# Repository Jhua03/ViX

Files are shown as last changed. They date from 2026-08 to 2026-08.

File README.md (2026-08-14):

# Parker ViX250AH / ViX500AH + Raspberry Pi Pico 2 Controller

A practical, safety-oriented reference implementation for controlling a **Parker ViX250AH or ViX500AH** from a computer and a **Raspberry Pi Pico 2**.

The architecture deliberately separates configuration/status from real-time motion:

- a Raspberry Pi 5, laptop, desktop, or other USB-capable computer talks to **ViX X3 over RS-232**;
- the same computer talks to a **Pico 2 over USB**;
- the Pico 2 generates differential **STEP/DIR** for **ViX X4**, reads the X4 encoder copy, and supervises limits, ViX fault, E-stop, following error, and the X4 energise input.

This repository targets the **AH family only**. It is intended to work with both the **ViX250AH** and **ViX500AH**. Motor/encoder tuning is machine-specific; the included MX80L setup is an example, not a universal ViX tuning profile.

> **Safety:** a servo drive can move unexpectedly during setup, wiring mistakes, or controller development. Commission near the middle of travel, use a physical emergency stop, keep clear of moving hardware, and verify every input polarity before allowing motion. Do not copy the MX80L gains to a different motor/stage without validating them.

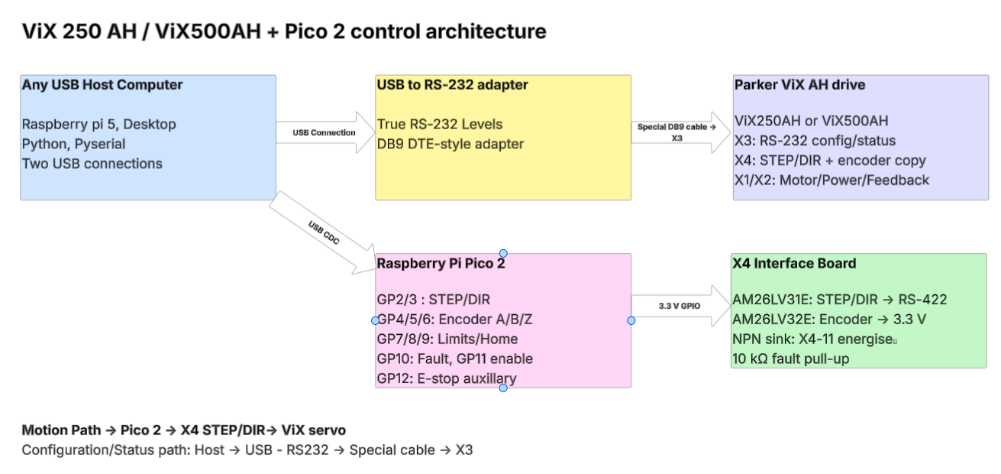
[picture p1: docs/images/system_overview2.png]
System overview


## Start here

1. Read [Hardware and wiring](docs/hardware-and-wiring.md).
2. Build the special [X3 RS-232 cable](docs/serial-x3.md).
3. Build the low-voltage [Pico 2 ↔ X4 interface](hardware/connector-pinouts.md) using the included schematic.
4. Follow [Software setup](docs/software-setup.md) to install Python/`pyserial` and flash the Pico 2.
5. Read [Safety](docs/safety.md) before energising the drive.
6. Follow [Commissioning](docs/commissioning.md) for first power-up and first controlled move.

## Repository layout

```text
ViX/
├── README.md
├── CHANGELOG.md
├── docs/                       User guide split by topic
│   └── images/                 Embedded SVG/PNG diagrams
├── hardware/
│   ├── schematic/              KiCad electrical source
│   ├── ViX_AH_Pico2_Wiring.drawio
│   ├── connector-pinouts.md
│   └── bom.md
├── datasheets/                 Parker + TI manufacturer PDFs
├── firmware/                   Pico 2 firmware
├── host/                       Simple supported Python CLI
├── scripts/                    Firmware build/upload helpers
├── tests/                      Offline checks for the cleaned repo
└── archive/commissioning-history/
                                Original v4.x development/commissioning material
```

## Hardware at a glance

For the X4 electrical interface this design uses:

- **AM26LV31E** — 3.3 V differential line driver for STEP/DIR;
- **AM26LV32E** — 3.3 V differential receiver for A/B/Z encoder copies;
- a small **NPN transistor** for fail-safe control of X4 pin 11;
- pull-ups for open-collector inputs where required.

See [the BOM](hardware/bom.md) for exact suggested parts, DigiKey Canada links, construction options, and local datasheets.

For breadboard work, the SOIC-16 ICs can be soldered to inexpensive **SOIC-16-to-DIP-16 adapter boards**. The adapters can be plugged into a breadboard, mounted on perfboard, **or used by themselves with wires soldered directly to their 0.1-inch pads**.

## X3 is not a normal straight-through DB9 cable

The ViX X3 connector uses an RS-232 pin assignment that is not the standard PC DB9 arrangement. A simple three-wire adapter cable is required.

For a typical USB-to-RS232 adapter with a male DB9 connector:

```text
USB-RS232 DB9            ViX X3
pin 3  TX   -----------> pin 4  RX
pin 2  RX   <----------- pin 5  TX
pin 5  GND  ------------ pin 3  GND
```

A convenient build uses a **female DB9 screw-terminal/breakout** at the USB-RS232 side and a **male DB9 breakout** at the ViX X3 side. See [X3 serial cable](docs/serial-x3.md) before building it; several X3 pins must intentionally remain unconnected.

## Simple host utility

Install the Python dependency:

```bash
python3 -m venv .venv
source .venv/bin/activate
python -m pip install -r requirements.txt
```

Typical commands:

```bash
python host/vix.py info --vix-port /dev/ttyUSB0 --pico-port /dev/ttyACM0 --axis 1
python host/vix.py status --vix-port /dev/ttyUSB0 --pico-port /dev/ttyACM0 --axis 1
python host/vix.py configure --profile io-only --confirm-inputs
python host/vix.py disable
```

The `jog` command intentionally requires explicit safety acknowledgements and currently uses the validated **MX80L 10 nm/count example profile**. Read [host/README.md](host/README.md) and [Commissioning](docs/commissioning.md) before using it.

## Documentation

- [Documentation index](docs/README.md)
- [Hardware and wiring](docs/hardware-and-wiring.md)
- [X3 serial connection and custom cable](docs/serial-x3.md)
- [Software setup](docs/software-setup.md)
- [ViX configuration](docs/vix-configuration.md)
- [Pico protocol and GPIO](docs/pico-protocol.md)
- [Safety and shutdown](docs/safety.md)
- [Commissioning](docs/commissioning.md)
- [MX80L tuning and measured performance](docs/tuning-and-performance.md)
- [Troubleshooting](docs/troubleshooting.md)

## Schematics and source files

The low-voltage X4 interface is supplied in three useful forms:

- **KiCad**: [`hardware/schematic/vix_pico_interface.sch`](hardware/schematic/vix_pico_interface.sch) — editable electrical schematic source;
- **SVG/PNG**: [`docs/images/x4_interface.svg`](docs/images/x4_interface.svg) — easy to read directly on GitHub;
- **draw.io**: [`hardware/ViX_AH_Pico2_Wiring.drawio`](hardware/ViX_AH_Pico2_Wiring.drawio) — high-level system, X3 cable, and X4 wiring diagrams.

X1 high-voltage/motor power and X2 motor-feedback wiring are intentionally not recreated as breadboard wiring. Use the correct Parker motor/harness and the included Parker manual for those connectors.

## Tested example: Parker MX80L, 10 nm encoder

The archived commissioning work used an MX80L configuration with:

```text
100,000 encoder counts/mm
100 counts = 1 µm
1 count = 10 nm
```

The current example tuning and measured small-move limitations are documented separately in [Tuning and performance](docs/tuning-and-performance.md). This separation is intentional: the electrical interface is generic to the supported ViX AH drives, while encoder scale and servo tuning depend on the attached motor/stage.

## Historical material

The original v4.x threshold-refinement package, release notes, audits, and agent handoff are preserved under [`archive/commissioning-history/`](archive/commissioning-history/). They are kept for traceability but are not the recommended starting point for a new user.

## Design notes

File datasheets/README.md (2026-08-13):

# Datasheets

| File | Component | Manufacturer page / purchase link |
|---|---|---|
| `Parker_ViX_AH_User_Guide.pdf` | Parker ViX AH servo-drive user guide | Original Parker manual supplied with this repository |
| `TI_AM26LV31E.pdf` | AM26LV31E 3.3 V differential line driver | https://www.ti.com/product/AM26LV31E |
| `TI_AM26LV32E.pdf` | AM26LV32E 3.3 V differential line receiver | https://www.ti.com/product/AM26LV32E |

DigiKey Canada purchase pages used by the hardware guide:

- AM26LV31EIDR: https://www.digikey.ca/en/products/detail/texas-instruments/AM26LV31EIDR/1895997
- AM26LV32EIDR: https://www.digikey.ca/en/products/detail/texas-instruments/AM26LV32EIDR/1896009

The local PDFs are included so the wiring can be reviewed offline. Check the manufacturer pages for later datasheet revisions before a new hardware spin.

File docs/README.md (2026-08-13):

# Documentation index

The original long-form ViX document has been reorganized into these task-focused guides:

| Document | Use it for |
|---|---|
| [Hardware and wiring](hardware-and-wiring.md) | System architecture, X4 electronics, construction choices |
| [X3 serial connection](serial-x3.md) | USB-RS232 adapter and the special three-wire DB9 cable |
| [Software setup](software-setup.md) | Python, `pyserial`, Pico 2 firmware build/flash |
| [ViX configuration](vix-configuration.md) | AH drive mode, X4 settings, volatile setup, readback |
| [Pico protocol](pico-protocol.md) | GPIO mapping, ASCII/JSON protocol, watchdog, status fields |
| [Safety](safety.md) | E-stop, enable/shutdown order, limits, faults |
| [Commissioning](commissioning.md) | First connection through first safe move |
| [Tuning and performance](tuning-and-performance.md) | MX80L 10 nm example only |
| [Troubleshooting](troubleshooting.md) | Serial, fault, encoder, limit, and motion problems |

For connector-level tables, use [`../hardware/connector-pinouts.md`](../hardware/connector-pinouts.md). For the parts list, use [`../hardware/bom.md`](../hardware/bom.md).

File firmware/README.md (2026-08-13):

# Pico 2 firmware

Firmware identity:

```text
vix-base-pico2-v2.7
protocol 5
```

This firmware is for **Raspberry Pi Pico 2 only**. It generates X4 STEP/DIR,
counts the ViX encoder copy, supervises limits/fault/E-stop/following error, and
controls the X4 hardware-energise transistor.

The authoritative GPIO mapping is in `src/board_config.h` and is summarized in
[`../hardware/connector-pinouts.md`](../hardware/connector-pinouts.md).

## Build

From the repository root, create/activate a Python environment and install
PlatformIO if you do not already have it:

```bash
python3 -m venv .venv
source .venv/bin/activate
python -m pip install --upgrade pip platformio
```

Install the native build prerequisites for your OS (CMake, Ninja and an Arm
embedded GCC toolchain), install/clone the official Raspberry Pi Pico SDK, then:

```bash
export PICO_SDK_PATH="$HOME/pico-sdk"
bash scripts/build_and_verify_firmware.sh
```

The expected output is:

```text
firmware/build-pio/vix_base_pico2_controller.uf2
```

The PlatformIO project is only a task/front-end; the actual firmware build is
performed by the official Pico SDK CMake/Ninja project.

## Upload

For the first upload, hold **BOOTSEL** while plugging the Pico 2 into USB, then
run:

```bash
bash scripts/upload_firmware_bootsel.sh
```

You can also copy the UF2 manually to the Pico 2 mass-storage device.

## Guarded recovery is advanced commissioning functionality

The firmware contains:

```text
RECOVER START <100..2000 ms> I_UNDERSTAND
RECOVER STOP
```

This path was developed for tightly bounded recovery from particular stale ViX
fault states. It is separate from normal `ARM`/`ENABLE` and is **not** part of
the beginner commissioning workflow in the main guide.

Firmware independently bounds that recovery path with timeout, displacement,
heartbeat, E-stop/limit, encoder-validity, and fault-state checks. The normal
`ENABLE 1` path still refuses an active fault or safety latch.

For the full development rationale and tests, see
[`../archive/commissioning-history/v4_78/`](../archive/commissioning-history/v4_78/).

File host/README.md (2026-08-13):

# `vix.py` host utility

`vix.py` is the small, supported starting point for a ViX250AH/ViX500AH + Pico 2 installation. It is intentionally much simpler than the archived threshold-refinement runner.

## Install

From repository root:

```bash
python3 -m venv .venv
source .venv/bin/activate
python -m pip install -r requirements.txt
```

## Architecture

The process opens two independent serial links:

```text
--vix-port   USB-to-RS232 -> custom DB9 cable -> ViX X3
--pico-port  USB -> Pico 2
```

Motion is generated only by Pico STEP/DIR over X4. The script does not use ViX internal motion commands.

## Commands

### Identity

```bash
python host/vix.py info --vix-port /dev/ttyUSB0 --pico-port /dev/ttyACM0 --axis 1
```

### Status

```bash
python host/vix.py status --axis 1
```

### Apply volatile I/O configuration

```bash
python host/vix.py configure \
  --profile io-only \
  --confirm-inputs \
  --axis 1
```

The command leaves the drive OFF and Pico disarmed.

### MX80L 10 nm example configuration

```bash
python host/vix.py configure \
  --profile mx80l-10nm \
  --confirm-inputs \
  --axis 2
```

Only use this profile on a system you have validated for the included MX80L parameters.

### One complete jog transaction

```bash
python host/vix.py jog \
  --um 1 \
  --confirm-inputs \
  --i-understand \
  --axis 2
```

`jog` currently requires the `mx80l-10nm` profile. It performs the full enable/move/safe-disable transaction in one process so the watchdog heartbeat remains alive and shutdown is deterministic.

### Safe disable

```bash
python host/vix.py disable --axis 1
```

## Bench E-stop bypass

`--bench-no-estop` exists only for attended commissioning before a final E-stop auxiliary input is available. Do not use it for a completed machine.

## Soft limits and negative limit

Defaults are:

```text
--soft-min -50000
--soft-max  50000
```

Add `--has-negative-limit` only after a real negative-limit input has been physically tested. The archived MX80L machine had no working negative-limit input and used `HAS_LN=0`.

## What this utility intentionally does not do

It does not:

- save tuning/configuration with `SV`;
- change motor/feedback setup with `MOTOR`, `SETUPFB`, or `RFS`;
- perform ViX internal motion;
- run the advanced guarded stale-fault recovery workflow;
- claim that one motor's gains are safe for another motor.

For advanced historical characterization tools, see `archive/commissioning-history/v4_78/`.

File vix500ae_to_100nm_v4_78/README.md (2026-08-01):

# vix500ae_to_100nm_v4_78

Targeted threshold-refinement package for the ViX500AE/Base + MX80L + Pico2 setup.

Use after v4.77 found the best strong threshold at 40 counts / 400 nm using:

```text
damped_gi0p2_gp2_gv1p5_cl2
GF0 GI0.2 GP2 GV1.5 FT0, CL=2%
```

Run:

```bash
./scripts/run_offline_checks.sh

python3 host/vix100nm_commission.py \
  --stage 8 \
  --vix-port /dev/ttyUSB0 \
  --pico-port /dev/ttyACM0 \
  --bench-no-estop

./scripts/run_threshold_refinement.sh
```

Default amplitudes are 50, 40, 35, 30, 25, 20, 15, 10 counts, equal to 500, 400, 350, 300, 250, 200, 150, 100 nm.

The sweep validates the 400 nm threshold and tests conservative current/gain nudges:

```text
damped_gi0p2_gp2_gv1p5_cl2
damped_gi0p2_gp2_gv1p5_cl3
damped_gi0p2_gp2_gv1p5_cl4
damped_gi0p3_gp2_gv1p5_cl3
```

This is not final 100 nm validation. It is a threshold-refinement test to see whether the usable threshold can be pushed from 400 nm toward 300/250/200 nm. Stay present; the script commands real moves.

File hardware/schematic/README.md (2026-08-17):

# KiCad schematic

Keep `vix_pico_interface-cache.lib` in the **same directory** as the schematic. The schematic uses the cached custom symbols for the Pico 2, AM26LV31E, AM26LV32E, and the ViX X4 connector.

## Opening it

1. Keep both files together:
   - `vix_pico_interface.sch`
   - `vix_pico_interface-cache.lib`
2. Open `vix_pico_interface.sch` in KiCad Schematic Editor.
3. KiCad 8/9 may offer to convert it to the current `.kicad_sch` format. Save the converted copy if desired.

## What is represented

- GP2/GP3 -> AM26LV31E -> ViX X4 differential STEP/DIR.
- ViX X4 A/B/Z differential encoder outputs -> AM26LV32E -> GP4/GP5/GP6.
- X4 FAULT open-collector output -> GP10 with 10 kOhm pull-up to 3.3 V.
- GP11 -> 4.7 kOhm -> 2N3904 -> X4 ENERGISE input for `ES=0` operation.
- Pico GND is tied to X4 pin 3 control 0 V.
- GP7/GP8/GP9/GP12 are labelled for external limit, home, and E-stop auxiliary inputs.

This sheet is **only the low-voltage X4 interface**. The host computer communicates with the ViX separately through X3 RS-232.

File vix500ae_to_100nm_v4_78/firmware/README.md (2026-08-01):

# Pico 2 firmware v2.7

Identity:

```text
vix-base-pico2-v2.7
protocol 5
```

## Guarded recovery command

```text
RECOVER START <100..2000 ms> I_UNDERSTAND
RECOVER STOP
```

This command is separate from normal ARM/ENABLE. It may assert GP11 while the
ViX fault input is already active, solely so recoverable DF20/DF21 can enter a
valid enabled state and clear.

Firmware independently enforces:

- 2000 ms absolute maximum;
- 5000 counts / 50 µm raw displacement;
- 750 ms host heartbeat;
- E-stop and limits;
- invalid quadrature transitions;
- timeout latch;
- fault-clear then fault-reassert shutdown.

The normal `ENABLE 1` path still refuses an active fault or safety latch.

## Build and upload

From the package root:

```bash
source ~/Downloads/vix250ah_pico2_controller_v1/.venv/bin/activate
export PICO_SDK_PATH="$HOME/pico-sdk"
export PICOTOOL_EXECUTABLE="$HOME/.local/picotool-2.3.0/bin/picotool"
bash scripts/build_and_verify_firmware.sh
```

Expected output:

```text
firmware/build-pio/vix_base_pico2_controller.uf2
```

Then put the Pico 2 in BOOTSEL mode and run:

```bash
bash scripts/upload_firmware_bootsel.sh
```

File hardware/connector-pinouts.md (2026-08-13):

# Connector and Pico pinouts

## Pico 2 pins used by the included firmware

The firmware uses GPIO numbers, not header pin numbers. For the standard non-wireless Raspberry Pi Pico 2 board:

| Function | GPIO | Pico physical header pin |
|---|---:|---:|
| STEP logic | GP2 | 4 |
| DIR logic | GP3 | 5 |
| Encoder A | GP4 | 6 |
| Encoder B | GP5 | 7 |
| Encoder Z | GP6 | 9 |
| Positive limit | GP7 | 10 |
| Negative limit | GP8 | 11 |
| Home | GP9 | 12 |
| ViX fault | GP10 | 14 |
| Drive enable command | GP11 | 15 |
| E-stop auxiliary | GP12 | 16 |
| 3.3 V output | 3V3(OUT) | 36 |
| Ground | GND | 3, 8, 13, 18, 23, 28, 33, or 38 |

## ViX X3 - RS-232

X3 is a 9-way D-sub **socket** on the drive.

| X3 pin | Function | Use here |
|---:|---|---|
| 1 | Reserved | No connection |
| 2 | Drive reset/mode input | **Do not connect** during normal operation |
| 3 | RS-232 GND | Special cable ground |
| 4 | RS-232 Rx | From USB-RS232 adapter TX |
| 5 | RS-232 Tx | To USB-RS232 adapter RX |
| 6 | Reserved | No connection |
| 7 | RS-232 Tx (D-loop) | No connection for a single drive |
| 8 | Do not connect | **No connection** |
| 9 | +5 V output | **No connection** |

See [`../docs/serial-x3.md`](../docs/serial-x3.md) for the special cable.

## ViX X4 - STEP/DIR, encoder copy, fault and energise

X4 is a high-density 15-way D-sub socket. Use a **male HD15** mating connector or screw-terminal breakout.

| X4 pin | With `EI=0` / `EO=2` | Pico interface |
|---:|---|---|
| 3 | Control 0 V | Pico/interface GND |
| 4 | /Z encoder output | U2 receiver Z- |
| 5 | Z encoder output | U2 receiver Z+ |
| 6 | Fault, NPN open collector | GP10 + 10 kΩ pull-up to 3.3 V |
| 7 | STEP- input | U1 STEP- |
| 8 | DIR- input | U1 DIR- |
| 9 | A- encoder output | U2 A- |
| 10 | B- encoder output | U2 B- |
| 11 | Energise input | Q1 collector; active-low when `ES=0` |
| 12 | STEP+ input | U1 STEP+ |
| 13 | DIR+ input | U1 DIR+ |
| 14 | A+ encoder output | U2 A+ |
| 15 | B+ encoder output | U2 B+ |

X4 pins 1 and 2 are analogue-input pins and are not used by this controller.

## U1 - AM26LV31E wiring

| U1 pin | Name | Connection |
|---:|---|---|
| 1 | 1A | Pico GP2 STEP |
| 2 | 1Y | X4 pin 12 STEP+ |
| 3 | 1Z | X4 pin 7 STEP- |
| 4 | G | 3.3 V (enable drivers) |
| 5 | 2Z | X4 pin 8 DIR- |
| 6 | 2Y | X4 pin 13 DIR+ |
| 7 | 2A | Pico GP3 DIR |
| 8 | GND | GND |
| 9 | 3A | GND (unused channel input) |
| 10, 11 | 3Y, 3Z | No connection |
| 12 | /G | GND (enable drivers) |
| 13, 14 | 4Z, 4Y | No connection |
| 15 | 4A | GND (unused channel input) |
| 16 | VCC | 3.3 V + 100 nF to GND |

## U2 - AM26LV32E wiring

| U2 pin | Name | Connection |
|---:|---|---|
| 1 | 1B | X4 pin 9 A- |
| 2 | 1A | X4 pin 14 A+ |
| 3 | 1Y | Pico GP4 encoder A |
| 4 | G | 3.3 V (enable receivers) |
| 5 | 2Y | Pico GP5 encoder B |
| 6 | 2A | X4 pin 15 B+ |
| 7 | 2B | X4 pin 10 B- |
| 8 | GND | GND |
| 9 | 3B | X4 pin 4 Z- |
| 10 | 3A | X4 pin 5 Z+ |
| 11 | 3Y | Pico GP6 encoder Z |
| 12 | /G | GND (enable receivers) |
| 13 | 4Y | No connection |
| 14, 15 | 4A, 4B | No connection |
| 16 | VCC | 3.3 V + 100 nF to GND |

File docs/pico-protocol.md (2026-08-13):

# Pico 2 firmware, GPIO and protocol

## 1. GPIO mapping

The included firmware uses:

```text
GP2   STEP logic -> AM26LV31E -> X4 STEP pair
GP3   DIR logic  -> AM26LV31E -> X4 DIR pair
GP4   encoder A  <- AM26LV32E <- X4 A pair
GP5   encoder B  <- AM26LV32E <- X4 B pair
GP6   encoder Z  <- AM26LV32E <- X4 Z pair
GP7   positive limit
GP8   negative limit
GP9   home
GP10  ViX X4 fault
GP11  NPN hardware-enable control for X4 pin 11
GP12  E-stop auxiliary input
```

For physical header numbers, see [`../hardware/connector-pinouts.md`](../hardware/connector-pinouts.md).

## 2. USB serial format

The Pico uses native USB CDC, normally at `/dev/ttyACM0` on Linux. The host sends:

- ASCII text commands;
- newline termination;
- one command at a time.

The Pico answers with one-line JSON objects. The host checks the `ok` field and treats a rejected command as an error.

## 3. Core commands

| Command | Purpose |
|---|---|
| `PING` | basic communication check |
| `INFO` | firmware/system identity |
| `STATUS` | full current state |
| `CONFIG SHOW` | report configuration |
| `CONFIG <KEY> <VALUE>` | change runtime configuration |
| `ZERO` | zero the Pico encoder/command frame while disabled |
| `ARM I_UNDERSTAND` | arm after checks |
| `DISARM` | disarm |
| `ENABLE 0/1` | control the X4 hardware-enable transistor |
| `MOVE ...` | generate one STEP/DIR move |
| `ABORT` | abort motion |
| `CLEAR` | clear ordinary latches when allowed |
| `DIAG CLEAR` | clear diagnostic state |
| `HB` | watchdog heartbeat |

The archived commissioning firmware also contains a tightly bounded guarded-recovery command for specific stale ViX fault states. That is an advanced commissioning feature and is intentionally not part of the beginner workflow.

## 4. MOVE command

```text
MOVE <delta_counts> <max_rate_counts_s> <accel_counts_s2> <move_id>
```

`move_id` should be nonzero and unique. The host waits for both:

```text
motion == IDLE
move_completed_id == requested move_id
```

before treating a move as complete.

## 5. Runtime configuration used by the simple CLI

The generic Pico configuration includes:

```text
CONFIG LPOL 1
CONFIG LNPOL 0
CONFIG HPOL 1
CONFIG FPOL 1
CONFIG ENCSIGN 1
CONFIG DIRINV 0
CONFIG ESTOPREQ 1
CONFIG SOFTMIN -50000
CONFIG SOFTMAX 50000
CONFIG FERRMAX 5000
CONFIG WATCHDOG_MS 750
```

`HAS_LN`, `ESTOPREQ`, and `CONFIRM_INPUTS` are selected from CLI arguments. `ENCSIGN=1` matches the latest included firmware/wiring package; older long-form notes that said `-1` are superseded for this repository state.

## 6. Heartbeat

When armed/enabled, the host sends `HB` approximately every 100 ms. The default watchdog is 750 ms. The heartbeat runs in a separate thread so a blocked main command loop does not silently stop watchdog service.

A heartbeat is **not** a substitute for the explicit shutdown sequence. On exit or error, the host still attempts ABORT, hardware-disable, DISARM, and ViX OFF.

## 7. Useful STATUS fields

Expect fields such as:

```text
motion
armed
enabled
zeroed
latched
latch
encoder_position
command_position
following_error
encoder_invalid
limit_pos_active
limit_neg_active
home_active
fault_active
estop_safe
move_completed_id
```

Treat an unexpected increase in `encoder_invalid`, a latch, a ViX fault, an unsafe limit/E-stop, or excessive following error as a reason to stop commissioning and diagnose the hardware.

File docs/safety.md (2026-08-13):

# Safety and shutdown policy

This repository controls a real servo drive. Software safety is supplementary to physical guarding, correct power wiring, a real emergency-stop circuit, and the ViX's own protections.

## Non-negotiable software rules

1. Keep the ViX **OFF** while changing configuration.
2. Do not use ViX internal motion commands for this controller; motion goes through Pico `MOVE` and X4 STEP/DIR.
3. Do not issue `SV`, `MOTOR`, `SETUPFB`, or `RFS` from the normal host workflow.
4. The Pico hardware-enable path must be active **before** sending ViX `ON`.
5. Remove Pico hardware enable **before** sending ViX `OFF` during shutdown.
6. Abort on any safety latch, ViX fault, active movement limit, invalid encoder transition increase, E-stop, communication failure, or operator stop.
7. Do not automatically resume after a safety latch. Require operator inspection/acknowledgement.
8. Use a real E-stop auxiliary input in the completed machine.
9. Treat gain/current changes and initial energisation as hazardous operations.

## Normal enable sequence

A safe commissioning transaction follows this order:

```text
1. Open Pico and ViX serial ports.
2. ViX OFF.
3. Apply X4 configuration.
4. Read back ViX configuration.
5. Configure Pico while disabled/disarmed.
6. Clear permitted latches/diagnostics.
7. ZERO while disabled.
8. ARM.
9. Start heartbeat.
10. Pico ENABLE 1.
11. Wait briefly (~50 ms).
12. ViX ON.
13. Allow servo pull-in/settling.
14. Re-read status before commanding motion.
```

Do not send `ZERO` after the Pico is armed/enabled; use a software coordinate offset if you need a local GUI zero after energisation.

## Shutdown / fault sequence

The software attempts every step independently so one communication failure does not prevent later stop actions:

```text
Pico ABORT
Pico ENABLE 0
Pico DISARM
ViX OFF
stop heartbeat
```

After a fault, record Pico status and the ViX fault word before clearing diagnostic evidence.

## E-stop policy

For a completed machine, run with E-stop supervision required. Bench bypass (`--bench-no-estop`) exists only for attended commissioning where the final auxiliary contact is not yet wired. Do not make bench bypass the normal production configuration.

The included example assumes a normally-closed E-stop auxiliary loop whose broken/pressed state becomes unsafe. Physically verify your implementation before trusting it.

## Limits and soft limits

Hard limit inputs protect travel only if they are physically installed, wired, and configured with the correct polarity. Software soft limits add another layer but are relative to the coordinate origin established by the controller.

The included generic default `-50000..+50000` counts is intentionally a small commissioning window. On the MX80L 10 nm example that equals ±0.5 mm. For another encoder scale it represents a different physical distance.

## First energisation

Do it near the center of travel with:

- the mechanism mechanically clear;
- a physical E-stop within immediate reach;
- conservative current/tuning already established for the attached motor;
- verified encoder direction and limit polarity;
- no person or fragile equipment in the path.

If the stage pulls hard in one direction, chatters, runs away, or the encoder sign is wrong, disable immediately and diagnose before trying again.

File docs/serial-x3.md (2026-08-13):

# ViX X3 serial connection and custom DB9 cable

## 1. Host-side equipment

You need:

- any USB-capable host computer (Raspberry Pi 5, laptop, desktop, mini PC, etc.);
- a **true USB-to-RS232 adapter** that produces RS-232 electrical levels;
- the custom three-wire DB9 cable described below;
- a second USB cable for the Pico 2.

A USB-to-TTL/UART adapter is **not** the same thing as USB-to-RS232 and should not be connected directly to X3.

## 2. Why a special cable is required

ViX X3 is a DB9-style 9-way D-sub socket, but its RS-232 pins are not arranged like a standard PC serial DB9. Therefore a normal straight-through DB9 extension cable is not the documented connection.

X3 custom cable

For a standard PC-style USB-RS232 adapter whose DB9 uses pin 3 as TX, pin 2 as RX, and pin 5 as signal ground:

| USB-RS232 DB9 | Direction | ViX X3 |
|---|---|---|
| pin 3 TX | → | pin 4 RX |
| pin 2 RX | ← | pin 5 TX |
| pin 5 GND | — | pin 3 RS-232 GND |

Only these three conductors are required for a single-drive connection.

## 3. Easy cable build using two breakouts

For the common USB-RS232 adapter with a **male DB9** plug:

- use a **female DB9 screw-terminal/breakout** on the adapter side;
- use a **male DB9 screw-terminal/breakout** on the ViX side because X3 on the drive is a socket;
- connect only three wires:

```text
female breakout pin 3  -> male breakout pin 4
female breakout pin 2  -> male breakout pin 5
female breakout pin 5  -> male breakout pin 3
```

Label both ends before closing the cable. Continuity-check every pin with a multimeter before plugging it into the drive.

If your particular USB-RS232 adapter has a different connector gender, change only the mechanical mating arrangement; preserve the **signal-to-X3 mapping** above.

## 4. X3 pins to leave alone

For this project:

| X3 pin | Action |
|---:|---|
| 1 | no connection |
| 2 | **do not connect** during normal operation; this is associated with drive reset/mode behavior |
| 3 | RS-232 ground — use |
| 4 | RS-232 receive — use |
| 5 | RS-232 transmit — use |
| 6 | no connection |
| 7 | D-loop transmit — not needed for a single drive |
| 8 | **do not connect** |
| 9 | +5 V output — no connection |

## 5. Serial settings

The included host software uses:

```text
9600 baud
8 data bits
no parity
1 stop bit
no flow control
```

ViX commands are ASCII and are terminated by a carriage return (`\r`). The software axis address prefixes the command; for example, with axis address 1 the revision query is sent as `1R(RV)\r`.

The tested machine used axis address 2, but the CLI defaults to 1 because that is a common single-drive configuration. Always query/confirm the actual drive address and pass `--axis` explicitly when needed.

## 6. Linux device names

Typical Linux enumeration is:

```text
/dev/ttyUSB0   USB-to-RS232 adapter -> ViX X3
/dev/ttyACM0   Pico 2 native USB CDC
```

These names can change after reconnecting hardware. Use `ls -l /dev/ttyUSB* /dev/ttyACM*` or stable udev symlinks if this will become a permanent machine.

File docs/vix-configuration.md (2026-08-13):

# ViX250AH / ViX500AH configuration

## 1. What is generic and what is motor-specific

The X4 I/O mode is generic to this repository's ViX AH architecture. Servo gains, current limits, encoder scale, tracking limits, and motion acceptance criteria depend on the attached motor/stage.

The supported CLI therefore offers:

- `--profile io-only`: configure the ViX X4 interface only;
- `--profile mx80l-10nm`: additionally apply the included tested MX80L example tuning.

## 2. X4 interface configuration

The host sets the drive OFF before applying configuration and uses:

```text
MP
W(ES,0)
W(EI,0)
W(EO,2)
```

Meaning:

| Setting | Meaning in this project |
|---|---|
| `MP` | position mode for external pulse/direction control |
| `ES=0` | X4 energise input is active-low |
| `EI=0` | X4 command input uses STEP/DIR |
| `EO=2` | X4 encoder copy provides A/B quadrature outputs |

The host reads these values back before it will proceed with a motion transaction.

## 3. Volatile setup policy

The simple host utility intentionally does **not** issue:

```text
SV
MOTOR
SETUPFB
RFS
```

The guide assumes a drive whose motor/feedback base configuration has already been established correctly. Experiment-specific I/O/tuning values are applied volatilely so a commissioning mistake does not silently become the drive's permanent boot configuration.

## 4. Typical serial commands

Commands are prefixed with the ViX software axis address. Examples shown for axis 1:

```text
1R(RV)       read software revision
1STATUS      status report
1R(DF)       drive-fault word
1R(UF)       user-fault word (be aware of clear-on-read behavior in the ViX manual)
1OFF         de-energise
1ON          energise, only after the Pico hardware-enable path is safe and active
```

## 5. MX80L 10 nm example profile

Only use this profile with a machine whose motor/encoder/stage has actually been validated for it:

```text
GF = 0
GI = 0.2
GP = 2
GV = 1.5
FT = 0
CL = 2
PC = 100
TL = 13000
IM = 1
IW = 1000
```

The CLI applies these after setting `MP`, `ES=0`, `EI=0`, and `EO=2` when `--profile mx80l-10nm` is selected.

See [Tuning and performance](tuning-and-performance.md) for the example machine's scale and measured limitations.

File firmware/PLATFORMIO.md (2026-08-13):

# PlatformIO / official Pico SDK workflow

PlatformIO is used only as a convenient command/task front-end. The firmware is
configured and compiled by the official Raspberry Pi Pico SDK for
`PICO_BOARD=pico2`.

## Requirements

Install:

- Python 3 and PlatformIO;
- CMake;
- Ninja;
- an Arm embedded GCC toolchain;
- the Raspberry Pi Pico SDK.

Example Python setup:

```bash
python3 -m venv .venv
source .venv/bin/activate
python -m pip install --upgrade pip platformio
export PICO_SDK_PATH="$HOME/pico-sdk"
```

On Fedora, the native packages are typically along the lines of CMake, Ninja,
`arm-none-eabi-gcc*`, and newlib; exact package names vary by Fedora release.

## Command-line build

From repository root:

```bash
bash scripts/build_and_verify_firmware.sh
```

The script discovers `pio` from `PIO_EXECUTABLE`, the active `PATH`, or the
usual `~/.platformio/penv/bin/pio` location.

The resulting UF2 is:

```text
firmware/build-pio/vix_base_pico2_controller.uf2
```

## VS Code

Open the **repository root** or `firmware/` in VS Code with the PlatformIO
extension. The environment is named:

```text
pico2_official_sdk
```

The custom tasks are:

```text
SDK Build
SDK Upload
```

For the first upload, put the Pico 2 in BOOTSEL mode. Later upload behavior can
use picotool when the host permissions are configured.

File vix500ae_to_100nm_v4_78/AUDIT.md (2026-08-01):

# v4.10 engineering audit

## Verdict on v3

v3 was not ready for powered commissioning. The most important defect was that
it asserted the X4 enable input but never issued the required ViX `ON` command.
The zero-gain and gain-hold stages could therefore appear stable while the motor
was not energised.

Additional problems found were missing stage-order enforcement, a default gain
fallback, incomplete fault/invalid checks during shams, delayed Ctrl+C handling,
and acceptance criteria that relied too heavily on medians and sham span.

## Corrective actions in v4

1. Added X4-enable + serial-`ON` transaction and ST2.1 confirmation.
2. Added strict stage prerequisites and hardware/software state fingerprinting.
3. Removed guessed gains.
4. Added complete-run invalid-transition, latch, and DF checks.
5. Added bracketed Pico/ViX endpoint acquisition.
6. Added 95th-percentile and repeatability gates for the final 100 nm claim.
7. Added sham absolute-motion gates, not only sham range.
8. Added immediate KeyboardInterrupt cleanup.
9. Added mocked integration and adversarial offline tests.

## Known physical constraints retained

- Limit+ works: raw 1 active, raw 0 inactive.
- Limit- is unavailable and disabled by policy.
- Home works: raw 1 active, raw 0 inactive.
- No automatic homing or end search.
- Every powered stage creates a local zero and limits commands to +/-0.5 mm.
- Operator must confirm at least 1 mm physical clearance in both directions.
- Initial HE500 current clamp remains 1% to 2%, approximately 0.15 A to 0.30 A
  under the audited configuration.

## Release decision

Use v4.10 only. Flash Pico v2.3, run the offline checks, and run Stage 0. Do not run
Stage 1 until Stage 0 passes and the E-stop/hardware disconnect is ready.

## Additional v4.10 review

A second audit found no new route to bypass the staged gates, but added two
defensive controls before hardware release: explicit local target alignment using
`W(PA,0)` while OFF, and strict post-test proof that both the Pico enable output
and ViX ST2.1 are de-energised. Powered results are rejected if ST2.1 drops
unexpectedly during the measurement.

## v4.10 findings from the additional audit

The v4.1 release was not accepted unchanged. Two defects were found:

- **Pass-state/cleanup ordering:** stage functions wrote pass state before the
  context-manager cleanup. Cleanup errors were suppressed, so a failed
  de-energisation or restore could coexist with a saved pass flag.
- **Direction-probe baseline timing:** the initial encoder baseline was captured
  before energisation and could include enable-settling displacement.

v4.10 introduces strict cleanup error propagation, stage-in-progress crash
recovery, failure-driven downstream invalidation, and a post-energisation
direction baseline. It also expands exact Pico and ViX preflight readback.

## v4.19 audit note

The previous 234/250 result was caused by asynchronous PA/PE sampling. v4.19 forbids target inference from an unbracketed PA or PE value and preserves every accepted/rejected bracket in evidence.

## v4.19 forward audit

The following downstream failure modes were reviewed before release:

- slow zero-target settling from the Stage 2 gain;
- asynchronous PA/PE target reconstruction;
- opposite target sign before DIRINV correction;
- estimator precision tighter than serial timing supports;
- fixed waits in coarse, fine, and 100 nm ABBA tests;
- trace overflow when adaptive settling lengthens a block;
- Pico/ViX endpoint comparison at different timestamps;
- shams with unrealistically short dwell;
- carrying the Stage 2 hold gain into all later motion stages;
- stale Stage 3/downstream state after a gain or sign change.

The host now records a separate `motion_gains` state value selected by Stage 3.
Stages 4-7 cannot silently fall back to an uncharacterized higher gain.

## Final forward-audit findings corrected

1. Added an explicit v4.19 commissioning-policy fingerprint and v4.18 migration,
   preventing a previous Stage 3 pass from bypassing the new gain/settling rules.
2. Forced the first ABBA block to precede all shams and made trace selection
   deterministic.
3. Removed the 3-second sham cap; sham timing now follows measured settling up to
   the amplitude-specific endpoint budget.
4. Corrected current-firmware instructions to v2.6/protocol 5 and retained v2.5
   only as clearly labelled historical context.
5. Corrected the Stage 3 prompt to match the actual 20 µm hold and 50 µm probe
   safety windows.

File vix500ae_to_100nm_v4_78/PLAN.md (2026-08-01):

# ViX500AE + MX80L route to encoder-side 100 nm motion — v4.10

## Confirmed starting state

- Target drive: ViX500AE-Base, custom product CP13269 rev 3, HE500.
- Saved motor definition corrected to the 10 nm MX80L-D13 definition:
  `MOTOR(49420,1.6,1300000,138,80,4.75,1.80,4.500)`.
- ViX X4 quadrature copy and the Pico PIO count agreed exactly over more than
  1.5 million counts in both directions.
- Limit+ works and is active-high at the Pico input: raw 1 at the limit, raw 0 away from it.
- Limit- does not work and is excluded from the safety policy.
- Home works and is active-high: raw 1 at home, raw 0 away from home.
- Initial motion stays inside a manually centred +/-0.5 mm software window.

## Why firmware v2.3 is required

The v2.3 firmware adds four safeguards/measurement features before powered
commissioning:

1. A 750 ms host heartbeat lease. Loss of the laptop process disables X4-11.
2. Continuous following-error and limit checks even while holding with no MOVE
   active.
3. A real invalid-quadrature-transition counter driven by a rare-event PIO IRQ.
4. A 1 kHz on-Pico trace buffer for command position, encoder position,
   following error, invalid count, motion state and safety state.

## Stage gates

### Stage 0 - Input and identity preflight

No motion and no enable.

- Verify exact drive identity, corrected MOTOR definition, 75-85 V motor bus,
  and all DF bytes zero.
- Apply the runtime Pico policy:
  - `LPOL=1`
  - `HPOL=1`
  - `HAS_LN=0`
  - `FPOL=1`
  - `ENCSIGN=1`
  - software window `[-50000,+50000]` counts
  - watchdog 750 ms
- Require Limit+ to be inactive (`raw=0`) before arming.
- Home may read 0 or 1 depending on carriage location; it is a reference input,
  not a hard-stop input.

Gate: all checks pass.

### Stage 1 - Zero-gain enable smoke

- ViX temporary mode: MP, EI=0, EO=2, ES=0.
- `GAINS(0,0,0,0,0)`.
- CL=1% on HE500, approximately 0.15 A maximum.
- No STEP pulse. A pass is impossible unless the drive is confirmed energised.
- Start heartbeat, assert X4 enable, issue `ON`, and require `R(ST2)` to show ST2.1 motor-energised. Enable for 0.5 s with Pico trace, then drop X4 enable before `OFF`.

Purpose: validate X4 enable, fault polarity and absence of an enable transient
or unexpected torque before asking the position loop to hold.

Gate: no DF, no latch, no invalid transitions and no displacement beyond the
50 um firmware cutoff.

### Stage 2 - Low-gain hold ladder

Test, in order:

1. GP=0.10, GV=0.10
2. GP=0.25, GV=0.25
3. GP=0.50, GV=0.50
4. GP=1.00, GV=0.75
5. GP=2.00, GV=1.00

GF=GI=FT=0 during this stage. Each candidate is enabled for 1.5 s at CL=1%.
The stiffest stable candidate is repeated for 3 s at CL=2%, approximately
0.30 A maximum.

Gate: actual energisation confirmed, no fault/latch/invalid transition, no runaway, and bounded tail motion.
The selected gains are stored in `~/vix100nm_state.json`.

### Stage 3 - Direction and scale probe

- Command +1000 pulses, equal to 10 um at 10 nm/count.
- Rate 1000 counts/s.
- Compare Pico encoder change and ViX PA change.
- If direction is reversed, disable, toggle `DIRINV`, re-zero and retry once.

Gate:

- positive commanded response;
- 1000 +/- 5 encoder counts;
- Pico and ViX changes agree within 2 counts.

### Stage 4 - Coarse functional ladder

ABBA tests at:

- 100 um = 10000 counts
- 10 um = 1000 counts
- 1 um = 100 counts

CL=2%, local +/-0.5 mm window, both directions, no-command shams and first-block
1 kHz traces.

Gate: correct direction on every leg, response within 2% or five counts,
Pico/ViX agreement within two counts, clean faults and invalid counter.

### Stage 5 - Fine screening ladder

ABBA plus sham tests at:

- 1 um = 100 counts
- 500 nm = 50 counts
- 200 nm = 20 counts
- 100 nm = 10 counts

The runner stops at the first amplitude that fails. This is an efficient screen,
not the final 100 nm claim.

### Stage 6 - Final 100 nm validation

- 24 ABBA blocks.
- 96 commanded 10-count legs.
- 12 interleaved no-command sham holds.
- 100 counts/s, so each 100 nm command is generated over 0.1 s.

Gate:

- at least 95% correct-direction responses;
- median response 8-12 counts;
- no more than one wrong-direction leg;
- median ABBA closure <=3 counts;
- Pico/ViX path disagreement <=2 counts;
- sham span <=6 counts;
- no drive faults and no invalid quadrature transitions.

Passing this stage supports the statement: **the system commanded and measured
100 nm using its own 10 nm encoder path**. It is not independent physical
metrology because no interferometer is present.

### Stage 7 - Optional 30 nm / 20 nm stretch tests

Only after Stage 6 passes:

- 30 nm = 3 counts
- 20 nm = 2 counts
- 32 ABBA blocks and 20 shams per amplitude

These are quantised encoder-count experiments. They should not be described as
independently verified physical displacement.

## What remains deliberately excluded

- Automatic homing.
- Negative-limit search.
- Full-travel motion.
- Non-volatile gain or mode changes.
- MOTOR, SETUPFB, RFS or SV commands.
- Current above the initial CL=2% commissioning clamp.

## Mandatory ordering and reset policy

The runner refuses to enter a stage unless the preceding stage is recorded as passed for the exact drive/MOTOR/Pico fingerprint. Rerunning an earlier stage clears all later pass flags so stale evidence cannot unlock 100 nm validation.

## Fault recovery gate

Each stage begins by clearing only stale DF bit 20/21 signatures in a verified
non-energising transaction. Any other DF bit prevents commissioning from
continuing.

## Stage 3 v4.19 decision logic

The small probe classifies independent sign domains before evaluating final
settling. ViX PT is the command-domain reference, ViX PA is the drive feedback
reference, and the Pico encoder copy is compared against PA. The full probe only
passes after command scale, physical direction, cross-reader agreement, and
settling are all independently demonstrated.

## Guarded recovery gate added in v4.19

Any preflight DF20/DF21 is handled before motion-stage setup by the bounded
Pico v2.6 recovery transaction described in the release notes. No other DF is
automatically cleared.

## v4.19 Stage 3 decision path

1. Coherent 250-count sign probe. 2. Apply ENCSIGN/DIRINV correction. 3. Three coherent 250-count verifications. 4. Slower-rate diagnosis only after repeated mismatch. 5. 1000-count adaptive settling.

## v4.19 execution plan

1. Preserve passed Stages 0-2.
2. Run all bounded zero-target motion-gain candidates.
3. Select the best stable candidate using PE, tail span, and settling time.
4. Resolve encoder-copy sign and STEP/DIR direction independently.
5. Verify signed 250-count commands at the fastest passing STEP rate.
6. Verify signed 1000-count commands.
7. Reuse the selected motion gain for adaptive coarse/fine/final ABBA stages.
8. Stop only for a real safety, integrity, tuning-range, or acceptance failure;
   do not stop for a single missing serial payload, a moving target-estimator
   bracket, or a fixed dwell expiring.

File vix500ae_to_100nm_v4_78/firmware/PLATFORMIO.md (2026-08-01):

# PlatformIO / official Pico SDK workflow

The PlatformIO project is only a VS Code task front-end. The firmware itself is
built by the official Raspberry Pi Pico SDK for `PICO_BOARD=pico2`.

## Requirements

```bash
sudo dnf install -y cmake ninja-build arm-none-eabi-gcc-cs \
  arm-none-eabi-gcc-cs-c++ arm-none-eabi-newlib
export PICO_SDK_PATH="$HOME/pico-sdk"
```

Open VS Code from the shell that contains `PICO_SDK_PATH`:

```bash
code /path/to/vix500ae_to_100nm_v4_20/firmware
```

Use:

```text
Project Tasks -> pico2_official_sdk -> Custom -> SDK Build
Project Tasks -> pico2_official_sdk -> Custom -> SDK Upload
```

The resulting file is:

```text
build-pio/vix_base_pico2_controller.uf2
```

For the first upload, hold BOOTSEL while connecting the Pico 2. Later uploads
can use picotool when Fedora udev permissions are installed.

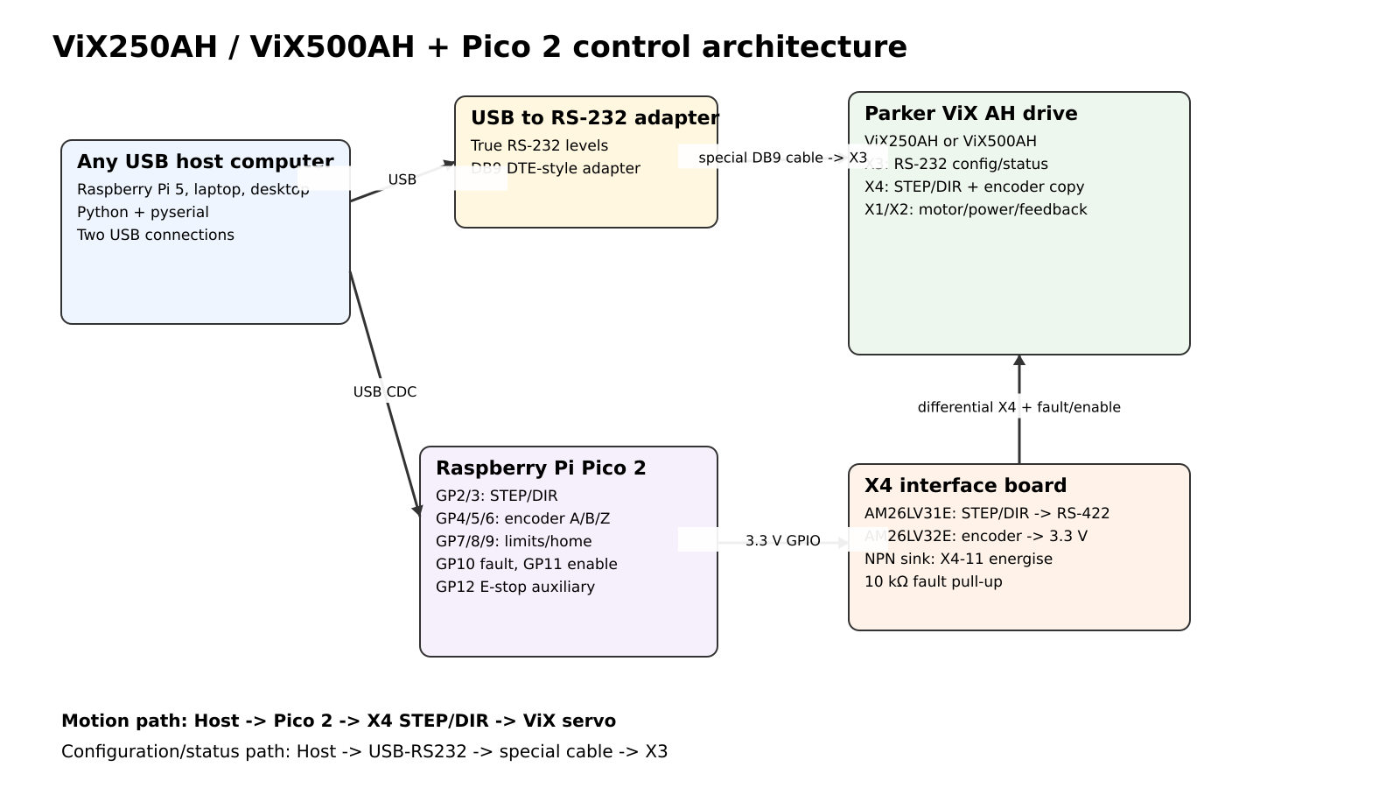
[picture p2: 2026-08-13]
docs/images/system_overview.png

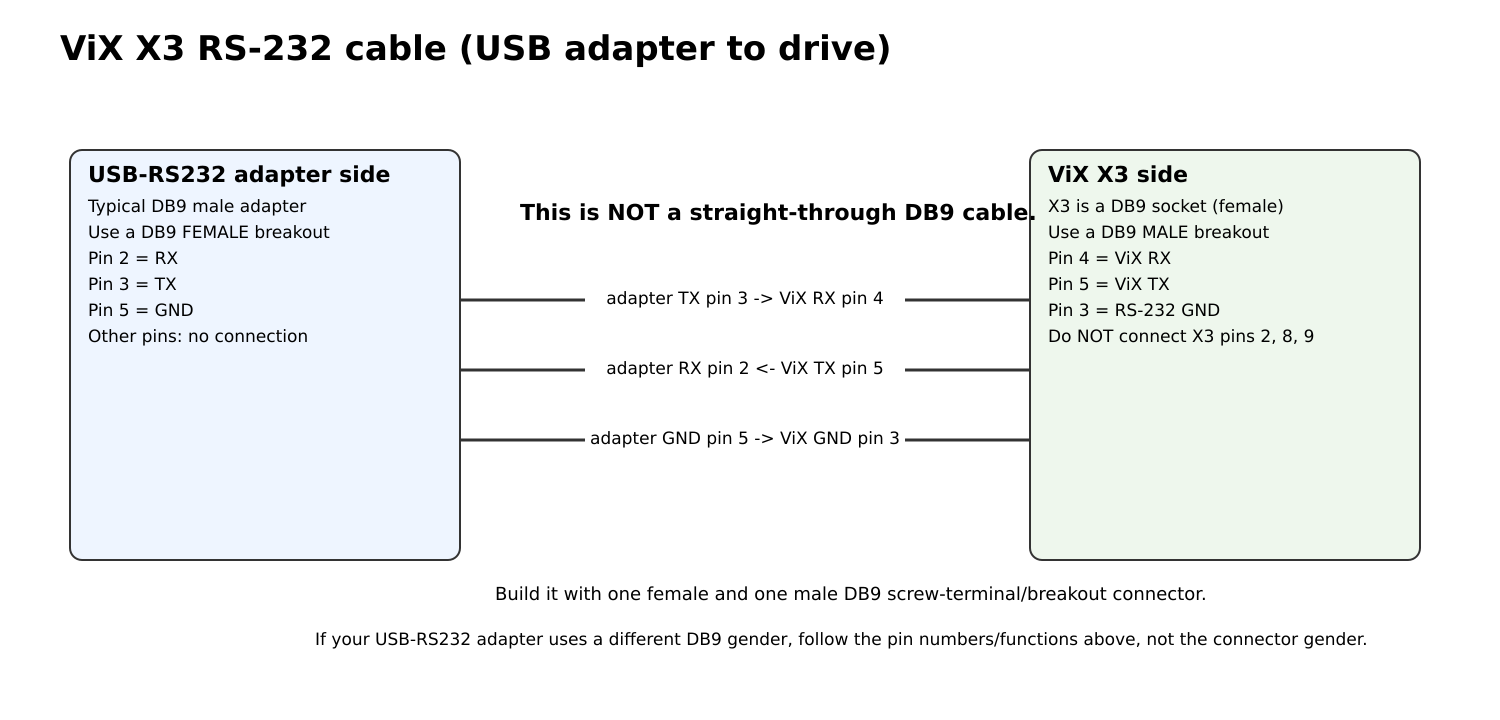
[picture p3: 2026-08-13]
docs/images/x3_cable.png

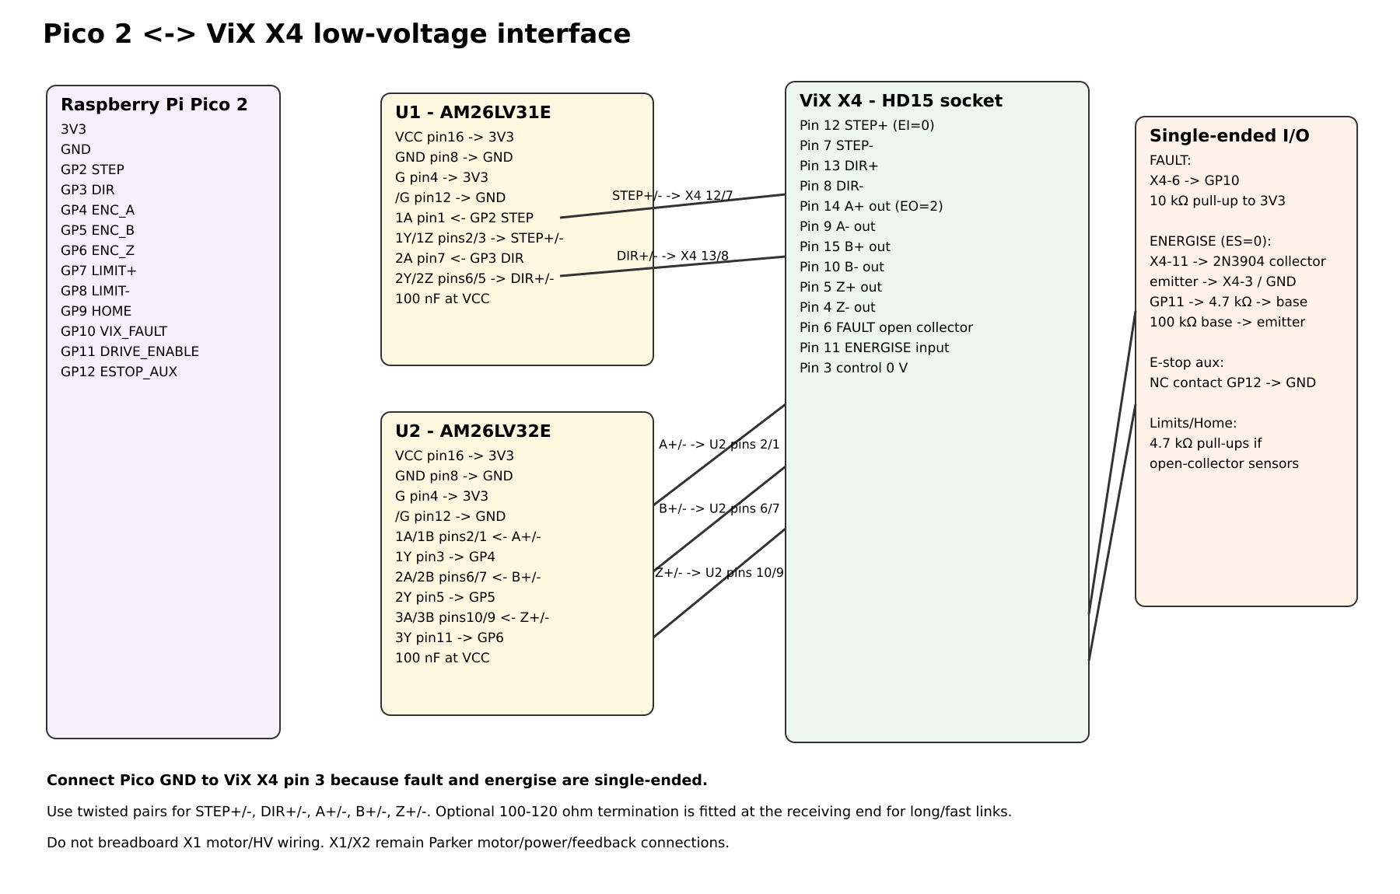
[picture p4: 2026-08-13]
docs/images/x4_interface.png

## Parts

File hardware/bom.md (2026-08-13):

# Pico 2 / ViX AH interface BOM

This is the low-voltage interface between a **Raspberry Pi Pico 2** and the **X4 connector of a Parker ViX250AH or ViX500AH**. X1 motor/HV and X2 motor-feedback wiring are intentionally outside this BOM.

## Required interface parts

| Qty | Ref | Part | Purpose | Package / build note | DigiKey Canada |
|---:|---|---|---|---|---|
| 1 | U1 | Texas Instruments **AM26LV31EIDR** | 3.3 V differential line driver for STEP and DIR | 16-SOIC | https://www.digikey.ca/en/products/detail/texas-instruments/AM26LV31EIDR/1895997 |
| 1 | U2 | Texas Instruments **AM26LV32EIDR** | 3.3 V differential receiver for encoder A/B/Z | 16-SOIC | https://www.digikey.ca/en/products/detail/texas-instruments/AM26LV32EIDR/1896009 |
| 1 | Q1 | 2N3904 or equivalent small-signal NPN | Pulls X4 pin 11 low to energise when `ES=0` | TO-92 is easiest for breadboard | Any reputable 2N3904 |
| 1 | R1 | 4.7 kΩ | Pico GP11 to Q1 base | 1/4 W through-hole or SMD | — |
| 1 | R2 | 100 kΩ | Q1 base-to-emitter pull-down | 1/4 W through-hole or SMD | — |
| 1 | R3 | 10 kΩ | ViX X4 fault pull-up to 3.3 V | 1/4 W through-hole or SMD | — |
| 2 | C1, C2 | 100 nF ceramic | Local decoupling at U1/U2 | Place directly at VCC/GND | — |
| 0–5 | RTERM | 100–120 Ω | Optional differential termination at receiving end | DNP for short bench wiring unless needed | — |
| 1 | J1 | HD15 male connector/breakout | Mates with ViX X4 high-density 15-way socket | VGA-style 3-row HD15, **male** | — |
| 1 | — | Raspberry Pi Pico 2 | Pulse generation, encoder counting, safety supervisor | Pico 2 only | — |

The included TI datasheets are in [`../datasheets/`](../datasheets/).

## SOIC-to-DIP option for breadboard wiring

U1 and U2 are easy to use without designing a PCB. Buy two generic **SOIC-16 to DIP-16 adapter/breakout boards**, solder one IC onto each adapter, then either:

- plug the adapters directly into a solderless breadboard;
- solder wires directly to the breakout-board through-holes and heat-shrink the connections; or
- mount the breakout boards on perfboard if you want a more permanent prototype.

A separate perfboard is **not required**. For a compact prototype, the SOIC-to-DIP board itself can be the wiring point: solder the chip to it and solder the X4/Pico wires directly to its 0.1-inch pads.

## PCB implementation

For a PCB, place U1/U2 close to the X4 connector, keep each differential pair routed together, and place the 100 nF decoupling capacitors directly beside pins 16 and 8. Provide optional 120 Ω termination footprints so they can be populated only if signal-integrity testing requires them.

## Why these line-interface ICs

The ViX AH manual shows 26LS32-family differential receivers on the X4 inputs and 26LS31-family differential drivers on the X4 encoder outputs. AM26LV31E and AM26LV32E provide the corresponding RS-422-style functions while operating from a 3.3 V supply, making them convenient for Pico 2 GPIO.

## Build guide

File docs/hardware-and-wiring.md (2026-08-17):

# Hardware and wiring

## 1. System architecture

System overview

There are **two independent USB paths** from the host computer:

```text
Host computer
├── USB -> Pico 2
│          └── X4 interface -> ViX STEP/DIR, encoder copy, fault, energise
└── USB -> true USB-to-RS232 adapter
           └── custom 3-wire DB9 cable -> ViX X3
```

The host can be a Raspberry Pi 5 or any practical computer with USB and Python 3. The Pico does **not** replace X3 serial communication: X3 is used to configure/query the ViX, while the Pico supplies the externally commanded motion path through X4.

## Physical drive reference

The original ViX document included these Parker reference figures for identifying the drive and XL supply arrangement:

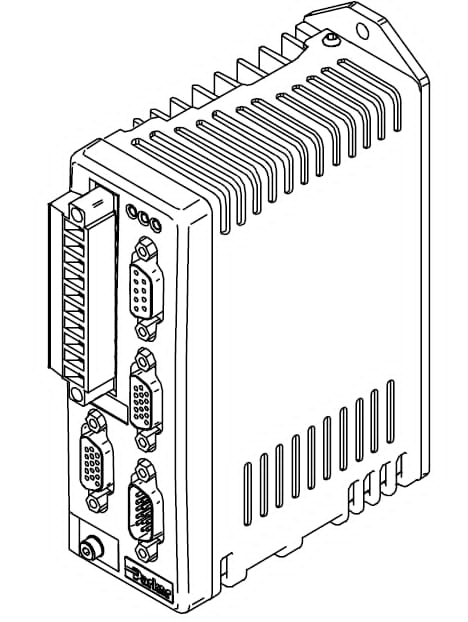
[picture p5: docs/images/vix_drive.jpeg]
ViX AH drive


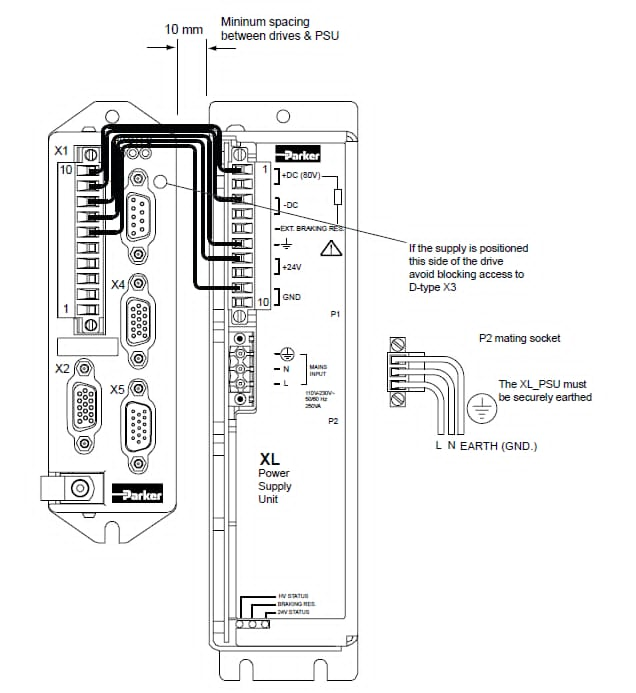
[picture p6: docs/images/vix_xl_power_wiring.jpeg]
ViX and XL power supply reference


Use these only as physical/reference illustrations; follow the Parker manual for X1 high-voltage/motor wiring and protective-earth requirements.

## 2. What connects to X4

The ViX X4 connector provides the signals needed by this project when the drive is configured for external STEP/DIR and encoder-copy output:

- differential STEP input;
- differential DIR input;
- differential A/B/Z encoder-copy outputs;
- open-collector fault output;
- active-low energise input when `ES=0`;
- control 0 V.

See the exact [X4 pin table](../hardware/connector-pinouts.md#vix-x4---stepdir-encoder-copy-fault-and-energise).

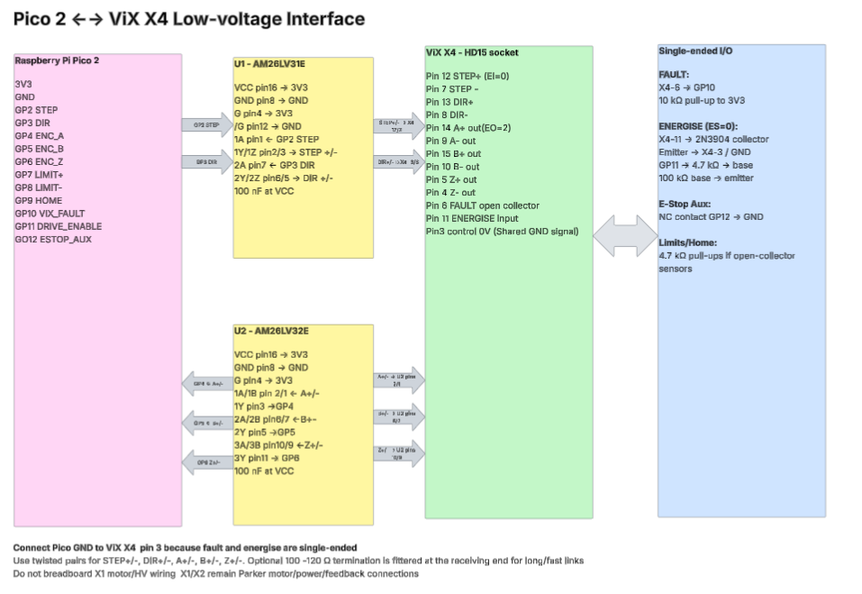
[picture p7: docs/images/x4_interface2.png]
X4 interface


## 3. Why line-interface ICs are used

Pico GPIO must not be wired directly to the differential X4 STEP/DIR or A/B/Z pairs. The interface uses:

- **U1 AM26LV31E** as the 3.3 V differential driver for STEP and DIR;
- **U2 AM26LV32E** as the 3.3 V differential receiver for A, B, and Z.

The parts and their local datasheets are listed in [`../hardware/bom.md`](../hardware/bom.md).

### STEP/DIR path

```text
Pico GP2 STEP -> U1 -> X4 STEP+ / STEP-
Pico GP3 DIR  -> U1 -> X4 DIR+  / DIR-
```

### Encoder-copy path

```text
X4 A+ / A- -> U2 -> Pico GP4
X4 B+ / B- -> U2 -> Pico GP5
X4 Z+ / Z- -> U2 -> Pico GP6
```

### ViX fault input to Pico

X4 fault is treated as an open-collector signal. The project uses a **10 kΩ pull-up to 3.3 V** at the Pico side:

```text
healthy: ViX transistor sinks -> GP10 raw 0
fault:   output releases      -> pull-up -> GP10 raw 1
```

Do not pull this node above the Pico's 3.3 V logic rail.

### Hardware energise

With `ES=0`, X4 pin 11 must be pulled low to permit energisation. GP11 therefore drives an NPN transistor rather than wiring the Pico directly to X4-11:

```text
GP11 LOW  -> transistor OFF -> X4-11 released -> hardware disabled
GP11 HIGH -> transistor ON  -> X4-11 low      -> hardware enabled
```

Use a 4.7 kΩ base resistor and a 100 kΩ base-emitter pull-down so the default/reset state remains disabled.

## 4. Limits, home and E-stop

The included firmware assigns:

```text
GP7  positive limit
GP8  negative limit
GP9  home
GP12 E-stop auxiliary input
```

The archived MX80L test machine used open-collector stage sensors and a normally-closed E-stop auxiliary loop. **Do not assume those polarities for another machine.** Verify inactive and active raw states physically before setting `CONFIRM_INPUTS 1`.

For the tested MX80L setup, the negative limit was unavailable and firmware policy used `HAS_LN=0`. That limitation is an example-machine condition, not a requirement of ViX250AH/500AH.

## 5. Construction choices

### Solderless breadboard

Use one SOIC-16-to-DIP-16 breakout for U1 and one for U2. Solder the ICs to the adapters and plug the adapters across the breadboard center gap. Keep differential pair wiring short and paired.

### Adapter-board-only wiring

A separate breadboard or perfboard is **not required**. You may:

1. solder each SOIC IC to a SOIC-16-to-DIP-16 adapter;
2. solder Pico/X4 wires directly to the adapter's 0.1-inch through-holes;
3. add the 100 nF capacitor across VCC/GND directly on the adapter;
4. insulate the finished assembly with heat-shrink or place it in an enclosure.

This is convenient for a one-off cable interface.

### Perfboard

Use the DIP-adapter boards as modules on perfboard. Add a header for the Pico and screw terminals or a cabled HD15 male for X4.

### PCB

The KiCad schematic under [`../hardware/schematic/`](../hardware/schematic/) is the electrical starting point. On a PCB, place U1/U2 and their 100 nF capacitors near the X4 connector and route each differential pair together. Optional termination footprints are useful for longer/noisier cable runs.

## 6. X1 and X2 are deliberately outside this breadboard interface

This repository does not encourage hand-wiring the ViX high-voltage/motor path. X1 motor/power and X2 feedback connections must follow the Parker manual and the correct motor/feedback harness for the attached motor. The local manual is [`../datasheets/Parker_ViX_AH_User_Guide.pdf`](../datasheets/Parker_ViX_AH_User_Guide.pdf).

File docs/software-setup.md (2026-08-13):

# Software setup

## 1. Host computer requirements

The host does not have to be a Raspberry Pi. It needs:

- Python 3;
- one USB port for the Pico 2;
- one USB port for the USB-to-RS232 adapter connected to ViX X3;
- permission to open the two serial devices.

The small supported CLI uses **pyserial**.

## 2. Install the Python environment

From the repository root:

```bash
python3 -m venv .venv
source .venv/bin/activate
python -m pip install --upgrade pip
python -m pip install -r requirements.txt
```

`requirements.txt` currently contains:

```text
pyserial>=3.5
```

On Linux, if Python reports `Permission denied` for `/dev/ttyUSB0` or `/dev/ttyACM0`, add your user to the distribution's serial-device group (commonly `dialout` or `uucp`) and log in again, or create an appropriate udev rule.

## 3. Confirm both serial devices

With the Pico 2 and USB-RS232 adapter attached:

```bash
ls -l /dev/ttyACM* /dev/ttyUSB*
```

Then try the non-motion identity command:

```bash
python host/vix.py info \
  --vix-port /dev/ttyUSB0 \
  --pico-port /dev/ttyACM0 \
  --axis 1
```

If your ViX uses a different software axis address, change `--axis`.

## 4. Build the Pico 2 firmware

The firmware uses the official Raspberry Pi Pico SDK and targets **Pico 2 only**.

A typical Linux build requires CMake, an Arm embedded GCC toolchain, and the Pico SDK. Point `PICO_SDK_PATH` at your SDK checkout, then from the repository root run:

```bash
export PICO_SDK_PATH="$HOME/pico-sdk"
bash scripts/build_and_verify_firmware.sh
```

The expected UF2 is:

```text
firmware/build-pio/vix_base_pico2_controller.uf2
```

For details, see [`../firmware/README.md`](../firmware/README.md) and [`../firmware/PLATFORMIO.md`](../firmware/PLATFORMIO.md).

## 5. Flash the Pico 2

For the first flash:

1. disconnect the stage/drive enable path or otherwise make motion impossible;
2. hold **BOOTSEL** while connecting the Pico 2 over USB;
3. copy the UF2 to the Pico mass-storage device, or use:

```bash
bash scripts/upload_firmware_bootsel.sh
```

After flashing, reconnect the Pico's USB CDC serial port and run `python host/vix.py info ...` again.

## 6. Use the CLI

Read [`../host/README.md`](../host/README.md) before using commands that configure or move hardware. The normal progression is:

```text
info -> status -> configure -> commissioning checks -> one jog -> disable
```

Configuration is intentionally **volatile**; the supported utility does not issue `SV` to save experimental settings into the drive.

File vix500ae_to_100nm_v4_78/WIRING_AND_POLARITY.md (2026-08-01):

# Wiring and runtime input policy

## Pico pins

```text
GP2   STEP logic -> AM26LV31 -> ViX X4 STEP+/-
GP3   DIR logic  -> AM26LV31 -> ViX X4 DIR+/-
GP4   encoder A  <- AM26LV32 <- ViX X4 A+/-
GP5   encoder B  <- AM26LV32 <- ViX X4 B+/-
GP6   encoder Z  <- AM26LV32 <- ViX X4 Z+/-
GP7   Limit+
GP8   Limit- input, physically unavailable/non-working
GP9   Home
GP10  ViX X4 fault
GP11  drive-enable transistor controlling ViX X4 pin 11
GP12  NC E-stop auxiliary contact
```

## Confirmed stage sensor truth table

```text
Limit+ inactive: raw 0
Limit+ active:   raw 1

Limit-:          not working; HAS_LN=0

Home inactive:   raw 0
Home active:     raw 1
```

Runtime Pico configuration:

```text
CONFIG LPOL 1
CONFIG LNPOL 0
CONFIG HPOL 1
CONFIG HAS_LN 0
CONFIG FPOL 1
CONFIG ENCSIGN 1
CONFIG SOFTMIN -50000
CONFIG SOFTMAX 50000
CONFIG WATCHDOG_MS 750
CONFIG CONFIRM_INPUTS 1
```

The ViX X4 fault output is normally low when healthy and rises through the Pico
pull-up when the open-collector output releases on a fault. Therefore:

```text
healthy raw_fault = 0
fault   raw_fault = 1
```

With the recommended NC E-stop auxiliary loop:

```text
safe/open? No: closed contact pulls GP12 low -> raw 0 -> safe
pressed/broken wire: pull-up gives raw 1 -> unsafe
```

## Missing negative limit policy

The commissioning runner does not search for a negative limit and does not home
automatically. It establishes a temporary local zero near mid-travel and limits
command position to +/-50000 counts, equal to +/-0.5 mm.

## X4 energise handshake

With `ES=0`, ViX X4 pin 11 is active-low. GP11 drives an NPN sink:

```text
GP11 low  -> NPN off -> X4-11 released/high -> hardware disabled
GP11 high -> NPN on  -> X4-11 pulled low    -> hardware enabled
```

The ViX still requires the serial `ON` command. The host verifies actual motor
energisation using `R(ST2)` and ST2.1 before accepting any powered result.

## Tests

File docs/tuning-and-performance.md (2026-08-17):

# MX80L 10 nm example: tuning and measured performance

This page is deliberately separate from the general ViX250AH/ViX500AH guide. **Do not treat these values as universal ViX AH settings.** They describe the archived MX80L commissioning configuration.

## Encoder/stage scale

```text
100,000 counts = 1 mm
100 counts     = 1 µm
1 count        = 10 nm
```

Therefore:

| Command | Counts |
|---:|---:|
| 1 µm | 100 |
| 500 nm | 50 |
| 400 nm | 40 |
| 300 nm | 30 |
| 100 nm | 10 |

## Example servo profile

The current archived threshold-refinement profile is:

```text
GF = 0
GI = 0.2
GP = 2
GV = 1.5
FT = 0
CL = 2
PC = 100
TL = 13000
IM = 1
IW = 1000
```

The simple CLI exposes this as:

```text
--profile mx80l-10nm
```

## Firmware encoder sign

The latest included firmware/wiring package uses:

```text
ENCSIGN = 1
```

Older notes that recorded `ENCSIGN=-1` are historical and should not override the current `board_config.h` and wiring documentation.

## Where to find the full experiments

The complete sequence of v4.x release notes, audits, validation scripts, raw policies, and threshold-refinement tooling is preserved in:

[`../archive/commissioning-history/v4_78/`](../archive/commissioning-history/v4_78/)

Use that archive when reproducing the research/commissioning process; use the main documentation for a clean new installation.

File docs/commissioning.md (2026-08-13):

# Commissioning: first connection to first controlled move

This procedure assumes the ViX motor/feedback wiring and base motor configuration are already correct. It covers the host/X3 + Pico/X4 controller in this repository.

## 1. Power OFF checks

Before applying drive power:

- compare every X3 wire against [the custom cable table](serial-x3.md);
- compare every X4 wire against [`hardware/connector-pinouts.md`](../hardware/connector-pinouts.md);
- continuity-check ground and differential pair assignments;
- confirm U1/U2 are powered from **3.3 V** with local 100 nF decoupling;
- confirm GP11's NPN defaults OFF so X4-11 is released;
- confirm no 5 V source is tied to Pico GPIO;
- confirm the stage is near a safe middle-of-travel position.

## 2. Connect without motion

Connect both USB interfaces, activate the Python environment, and identify device names:

```bash
source .venv/bin/activate
ls -l /dev/ttyUSB* /dev/ttyACM*
```

Read identity/status only:

```bash
python host/vix.py info \
  --vix-port /dev/ttyUSB0 \
  --pico-port /dev/ttyACM0 \
  --axis 1
```

If this fails, do not continue. Use [Troubleshooting](troubleshooting.md).

## 3. Verify inputs physically

With the drive still not energised, read:

```bash
python host/vix.py status --axis 1
```

Operate each accessible limit, home, and E-stop input by hand and confirm the reported raw/active behavior changes exactly as intended. Also confirm the ViX fault input is healthy.

Only after this physical check should you use `--confirm-inputs`.

## 4. Apply interface configuration while remaining OFF

For a generic ViX AH installation whose motor tuning is already stored/managed separately:

```bash
python host/vix.py configure \
  --profile io-only \
  --confirm-inputs \
  --axis 1
```

For attended bench work before the final E-stop auxiliary is installed, `--bench-no-estop` exists, but the completed machine should not use it.

The command leaves the ViX OFF and the Pico disarmed.

## 5. MX80L 10 nm example only

If — and only if — the attached system is the validated MX80L/10 nm configuration documented in this repository, you may apply:

```bash
python host/vix.py configure \
  --profile mx80l-10nm \
  --confirm-inputs \
  --axis 2
```

The archived/tested machine used axis address 2. Your drive address may differ.

## 6. First one-transaction jog

The supported CLI does not leave the stage energized between separate shell commands. `jog` performs a complete configure → arm → heartbeat → enable → move → safe-disable transaction.

For the validated MX80L profile, an example 1 µm move is:

```bash
python host/vix.py jog \
  --profile mx80l-10nm \
  --um 1 \
  --confirm-inputs \
  --i-understand \
  --axis 2
```

Stay at the machine with the physical E-stop ready. For the first run, use conservative rate/acceleration and a central stage location.

On completion, the CLI reports commanded counts, pre/post Pico status, and measured encoder change, then attempts safe shutdown.

## 7. Acceptance sequence for the MX80L example

The original long-form commissioning document used ABBA-style small-move sequences. For the 10 nm/count stage:

```text
1 µm   = 100 counts
500 nm = 50 counts
400 nm = 40 counts
```

A useful validation sequence is:

```text
+100, -100, -100, +100 counts
+50,  -50,  -50,  +50 counts
+40,  -40,  -40,  +40 counts
```

Confirm that:

- no Pico latch occurs;
- no ViX drive fault occurs;
- `encoder_invalid` does not increase;
- every requested move ID completes;
- the stage settles before the next move;
- final closure is consistent with your application's requirement.

The archived v4.78 commissioning tools contain more extensive automated threshold tests. Use them only after the basic hardware/firmware path is understood and safe.

## 8. Always finish with a safe stop

You can explicitly request:

```bash
python host/vix.py disable --axis 1
```

This attempts Pico `ABORT -> ENABLE 0 -> DISARM`, followed by ViX `OFF`.

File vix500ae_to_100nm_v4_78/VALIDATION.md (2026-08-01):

# Validation performed for v4.20

## Static and offline checks

- Python syntax compilation: PASS.
- Host built-in `--self-test`: PASS.
- Shell script syntax (`bash -n`): PASS.
- C source strict syntax check with Pico-SDK interface stubs and
  `clang -std=c11 -Wall -Wextra -Werror`: PASS.
- Mocked ABBA integration covering X4 enable + `ON`, move completion, Pico/ViX
  endpoint agreement, shams, final faults, invalid-transition accounting, and
  final 100 nm acceptance: PASS.
- Adversarial acceptance tests confirm rejection of poor repeatability, excessive
  endpoint error, sham motion, ViX PE, invalid transitions, and unverified
  energisation: PASS.
- Stage 6 with an empty state is rejected before either serial port is opened:
  PASS.

## Not possible to prove offline

No software review can guarantee bug-free behaviour on the actual custom drive.
These remain hardware gates:

1. Official Pico SDK must build the UF2 on the user's Fedora system.
2. Stage 0 must confirm the real raw input states and exact drive fingerprint.
3. Stage 1 must prove X4 enable polarity, serial `ON`, ST2.1 energisation, and
   safe de-energisation on the real hardware.
4. Stages 2-6 must pass in order with evidence and no override of a failed gate.

The package is ready for **Stage 0**, not for jumping directly to 100 nm motion.

## v4.10 additions

- Mocked zero-alignment path covers ViX `W(PA,0)` plus Pico `ZERO`.
- Mocked powered integration verifies ST2.1 stays asserted during data collection
  and clears after the independent enable plus OFF shutdown.

## v4.10 additional tests

- Interrupted-stage marker recovery and downstream invalidation: PASS.
- Cleanup failure causes stage failure rather than a saved pass: PASS.
- Pico safe-state proof rejects enabled/armed/moving readback: PASS.
- Pico CONFIG SHOW exact readback comparison: PASS.
- Stage 3 baseline is acquired after verified energisation: code-path audit PASS.

## Final release checks added in v4.10

- Simulated 100-count enable transient is excluded from the +1000-count
  direction/scale measurement: PASS.
- A mocked failure during final OFF/Z cleanup propagates as a stage failure:
  PASS.
- Input confirmation remains false while raw Limit+/fault/E-stop states are
  being checked, then is enabled and read back only after they pass: code-path
  audit PASS.
- Reset cleanup now verifies OFF/ST2.1, saved `MT` mode, the complete corrected
  MOTOR definition, and all four DF bytes: code-path audit PASS.
- Source/package fingerprints and the complete extracted file checksums are
  verified by `scripts/run_offline_checks.sh`: PASS.

## v4.10 additional adversarial checks

- Reused completed move ID is automatically replaced and cannot false-complete: PASS.
- Completion requires matching active ID and non-MOVING state: PASS.
- Incomplete DF1..DF4 record is rejected: PASS.
- Arbitrary/non-finite saved gains are rejected: PASS.
- ABBA trace-full condition is a hard failure: source-path audit PASS.
- Firmware protocol fingerprint, powered invalid-transition latch, queue-init
  check, and signed-magnitude helpers: source audit PASS.

## Final v4.10 audit additions

- Extended Pico trace-dump timeout to 120 seconds because a 4096-sample JSON
  trace cannot reliably transfer over 115200-baud USB CDC within 15 seconds.
- Re-samples and re-validates Limit+, fault, Home and E-stop states after the
  ViX is forced OFF and again after `CONFIRM_INPUTS=1`.
- Tightened Stage 2 firmware following-error cutoff to 2000 counts.
- Requires settled ViX PE and Pico following error after the Stage 3 scale move.
- Added a PIO clock-divider range guard.
- Fixed the C declaration order caught by strict C11 compilation.

## v4.10 loader regression

- Complete `pico_sdk_tasks.py` executed with `__file__` absent: PASS.
- `$PROJECT_DIR/extra_scripts` import path resolution: PASS.
- `sdk_build`, `sdk_upload`, and `sdk_clean` registration: PASS.
- Source audit forbids `Path(__file__)` in the PlatformIO wrapper: PASS.

## v4.10 fault-recovery validation

- Exact `DF1=10000000`, `DF3=00010000` stale back-drive signature clears in
  the mock while Pico enable and ViX ST2.1 remain false: PASS.
- Motor-HV over-voltage test fault is rejected without sending `ON`: PASS.
- Incomplete or malformed DF reports are rejected: PASS.
- Recovery is called by every stage preflight and Stage 8 safe restore:
  source-path audit PASS.
- Historical v4.10 firmware-identity regression (`vix-base-pico2-v2.5`): PASS. Current v4.19 requires v2.6/protocol 5.

## v4.10 additional regression tests

- DF zero plus stale X4 fault-active input triggers a safe output refresh: PASS.
- Output refresh leaves Pico enable false and ViX ST2.1 de-energised: PASS.
- Permanently high/open X4 fault input remains a hard failure: PASS.
- Non-whitelisted DF faults still receive no `ON` clear transaction: PASS.

## v4.19 trace-budget regression

- 0.5 s hold selects 4096 samples at 1000 us: PASS.
- 1.5 s and 3.0 s holds remain below the protected 3600-sample budget: PASS.
- Complete disabled-before/enabled/disabled-after envelope is required: PASS.
- Requested capacity and period must match Pico TRACE INFO readback: PASS.
- TRACE INFO count must match dumped rows: PASS.
- Existing v4.10 state schema remains accepted: PASS.

## v4.19 Stage 3 regressions

- Opposite Pico/Vix PA signs correct `ENCSIGN`, not `DIRINV`: PASS.
- Negative ViX PT response corrects `DIRINV`: PASS.
- ViX PT verifies one STEP pulse per target count: PASS.
- Corrected +1000-count probe passes adaptive settling in the mock plant: PASS.
- Encoder sign readback is exact and persisted for downstream policy: PASS.
- Existing trace, safety, stale-fault, build-helper, and firmware audits: PASS.

## v4.19 packaging regressions

- Clean extracted package verifies `SHA256SUMS`: PASS.
- Manifest contains no `__pycache__` or `.pyc` entries: PASS.
- Offline checks create no bytecode inside the package tree: PASS.
- Adaptive Stage 3 sign/scale regression remains PASS.

## v4.19 serial-report regressions

- First `R(PT)` attempt echo-only, second attempt valid: PASS.
- Recovered numeric payload preserved exactly: PASS.
- Real `*E` receives no retry: PASS.
- Existing adaptive Stage 3 regression: PASS.
- Fresh-extraction checks and checksum manifest: PASS.

## v4.19 guarded-recovery validation

- Exact firmware/protocol identity updated to Pico v2.6 / protocol 5.
- Dedicated recovery command requires explicit DF20/DF21 acknowledgement.
- Internal 500-2000 ms deadline and RECOVERY_TIMEOUT latch audited.
- E-stop, limits, following error, invalid encoder and watchdog remain active.
- Initial fault may be ignored only until the line first clears; reassertion latches.
- Host applies zero gains, CL=1%, 50 um cutoff and complete trace.
- Normal completion proves serial OFF before X4 gate drop.
- DF-clear/X4-high physical fault is never auto-refreshed.
- Compatible v4.14 state migration preserves only Stages 0-2.

## v4.19 regressions

- Moving PA around a PE report is rejected as incoherent: PASS.
- Five stationary brackets reconstruct PT=250 exactly: PASS.
- Encoder-copy sign remains independent of STEP/DIR direction: PASS.
- Three-probe scale policy and slower-rate fallback source audit: PASS.
- Guarded DF20/DF21 firmware and host regressions: PASS.

## v4.19 comprehensive regressions

- Exact v4.18 moving-baseline PA/PE/PA sequence reconstructs target near zero:
  PASS.
- Large asynchronous PA outlier is rejected by robust target clustering: PASS.
- Target estimator derives a bounded 5-12 count uncertainty rather than
  hard-coding a false 2-count precision: PASS.
- Motion-gain values are restricted to the predefined zero-integral bounded
  candidate set: PASS.
- Signed positive and negative direction/scale probes: PASS.
- Adaptive endpoint settling replaces every commanded-leg fixed sleep: PASS.
- 100 micrometre and 100 nanometre first-block trace plans remain below 4096
  samples under worst-case adaptive settling: PASS.
- ABBA records contain settle time, settle goal, and settled status: PASS.
- Existing guarded DF20/DF21 recovery, fault polarity, Limit+, trace-envelope,
  firmware C11 syntax, PlatformIO helper, and clean-extraction tests: PASS.

## v4.19 final release audit

- v4.18 fingerprint migrates while preserving only Stages 0-2: PASS.
- v2.5 legacy fingerprint migrates directly to v4.19 policy: PASS.
- Stage 3/downstream gains, signs, and metrics are invalidated on migration: PASS.
- First ABBA event is a commanded block before any sham: source audit PASS.
- Sham dwell uses measured settling and amplitude-specific cap: source audit PASS.
- Current firmware documentation says v2.6/protocol 5: PASS.

## v4.20 validation addendum

- `python3 host/vix100nm_commission.py --self-test`: PASS.
- `python3 tests/offline_test.py`: PASS.
- `python3 tests/firmware_source_audit.py`: PASS.
- `python3 tests/firmware_c_syntax_test.py`: PASS.
- `python3 tests/build_helper_test.py`: PASS.
- `./scripts/run_offline_checks.sh`: PASS after regenerating `SHA256SUMS`.

v4.20 specifically validates the schema/policy migration, local PA/PT/PF/PE zero
transaction, and the no-escalation-after-unsettled-hold Stage 3 rule.

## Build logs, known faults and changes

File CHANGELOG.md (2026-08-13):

# Changelog

## Repository cleanup / AH guide

- Reworked the repository around **ViX250AH / ViX500AH + Pico 2** rather than a single ViX500AE/MX80L experiment.
- Replaced the agent-handoff-style root README with a user-facing GitHub guide.
- Split the long ViX document into topic-focused Markdown files.
- Added a custom **X3 RS-232 cable** guide and diagram.
- Added a complete low-voltage **Pico 2 ↔ X4** interface using AM26LV31E/AM26LV32E, with KiCad source, SVG/PNG exports, and draw.io source.
- Added BOM, connector pinouts, DigiKey Canada links, and manufacturer datasheets.
- Added breadboard/perfboard/PCB construction guidance, including SOIC-to-DIP adapter-board wiring.
- Added `host/vix.py`, a small host utility for identity/status, volatile configuration, safe shutdown, and one-transaction MX80L jogging.
- Corrected documentation inconsistencies from the long-form source, including the 50-count unit conversion and the latest firmware encoder sign.
- Moved the full development/commissioning history into `archive/commissioning-history/`.

## Historical v4.x commissioning series

The archived v4.19–v4.78 work progressively added and hardened:

- Pico 2 STEP/DIR pulse generation and encoder feedback;
- ViX X4 hardware-enable/fault handling;
- limits, E-stop, heartbeat, following-error, and latch policies;
- guarded stale-fault recovery and offline safety audits;
- repeatable small-movement characterization and threshold sweeps;
- the final v4.78 threshold-refinement sweep around the measured 400 nm region.

The complete per-version notes are preserved unchanged in [`archive/commissioning-history/v4_78/`](archive/commissioning-history/v4_78/).

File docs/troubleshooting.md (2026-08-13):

# Troubleshooting

## Host cannot open `/dev/ttyUSB0` or `/dev/ttyACM0`

Check enumeration:

```bash
ls -l /dev/ttyUSB* /dev/ttyACM*
```

If the device exists but access is denied, fix Linux serial-group/udev permissions. If it disappears/reappears under a different number, use the new path or create a persistent udev symlink.

## ViX does not answer X3 commands

Check these in order:

1. The adapter is **USB-to-RS232**, not USB-to-TTL UART.
2. The custom cable is not wired as a normal straight-through cable.
3. Adapter TX pin 3 reaches ViX X3 pin 4.
4. Adapter RX pin 2 reaches ViX X3 pin 5.
5. Adapter signal ground pin 5 reaches ViX X3 pin 3.
6. X3 pins 2, 8, and 9 have not been accidentally tied into the cable.
7. The port is 9600 8-N-1 with no flow control.
8. `--axis` matches the ViX software address.

Use a multimeter continuity test before assuming a software problem.

## Pico responds but STEP/DIR does not move the ViX

Check:

- U1 AM26LV31E has 3.3 V at VCC and ground at pin 8;
- both driver-enable pins are asserted as shown in the pin table;
- GP2/GP3 reach U1 inputs;
- U1 differential outputs reach the correct X4 STEP and DIR pins;
- ViX readback says `MP`, `EI=0`, and `ES=0`;
- GP11/NPN is actually pulling X4-11 low during the permitted enable window;
- ViX has also received serial `ON`.

The X4 hardware-enable and serial `ON` conditions are both part of the energisation path.

## Encoder position is missing or wrong direction

Check U2 power/enable and all three differential pairs. A/B polarity or channel swap can reverse/count incorrectly. The current included firmware expects `ENCSIGN=1`; do not change it simply to hide a wiring error. Verify physical direction deliberately.

An increasing `encoder_invalid` counter indicates invalid quadrature transitions and can point to wiring mistakes, noise, poor termination, a bad receiver, or excessive edge rate/speed.

## ViX fault reads active when healthy

The project expects the X4 fault output to be open-collector with a local 3.3 V pull-up. Healthy should read raw low and a fault should release the node high. Check the 10 kΩ pull-up, ground reference, and X4 pin 6 wiring.

## Limit/home is inverted

Do not change firmware polarity blindly. Measure the raw state inactive and active, then set the appropriate Pico polarity. Only set `CONFIRM_INPUTS 1` after the physical behavior has been verified.

## Stage moves on enable or pulls violently

Disable immediately. Possible causes include incorrect feedback setup, wrong encoder/motor direction, invalid motor configuration, unsuitable gains, or wiring problems. The generic X4 interface guide cannot supply a universal motor tuning; return to the Parker motor/feedback setup procedure for the attached motor.

## Small moves do not reach commanded distance

For the archived MX80L setup, digitally representable movement did not equal guaranteed mechanical movement. Stiction, breakaway force and servo deadband can dominate very small commands. Use [Tuning and performance](tuning-and-performance.md) and the archived threshold-refinement tests rather than assuming more current automatically fixes the problem.

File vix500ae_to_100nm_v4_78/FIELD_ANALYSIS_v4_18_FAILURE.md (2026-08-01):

# Field analysis: v4.18 Stage 3 baseline failure

Evidence bundle:
`20260729_211837_913716_direction_scale.zip`

## What happened

No STEP move was issued. After `W(PA,0)`, X4 enable, and `ON`, the conservative
`GP=2, GV=1` hold response moved slowly while the target remained approximately
zero.

Selected observed brackets:

| Attempt | PA1 | PE | PA2 | midpoint target estimate |
|---:|---:|---:|---:|---:|
| 1 | 189 | 172 | 157 | 1 |
| 2 | 137 | 111 | 91 | 3 |
| 5 | 1 | -4 | -11 | -1 |
| 10 | -112 | -112 | -112 | 0 |
| 14 | -129 | -132 | -131 | 2 |

The old v4.18 gate accepted only brackets with `abs(PA2-PA1) <= 2` counts. It
obtained four accepted rows out of the required five and aborted.

## Conclusion

- Encoder-invalid delta: zero.
- ViX DF1-DF4: zero.
- X4 fault input: healthy.
- Limit+: inactive.
- Target estimate: consistently near zero despite substantial PA motion.
- Root cause: overly strict stationary-sample policy plus a gain seed too weak
  for efficient downstream settling.

v4.19 therefore changes both the estimator and the motion-settling strategy,
rather than weakening one threshold.

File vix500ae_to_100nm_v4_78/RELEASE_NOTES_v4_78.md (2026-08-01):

# v4.78

Targeted threshold-refinement sweep after v4.77 found a strong threshold at 40 counts / 400 nm.

Changes:

- Adds `host/vix_threshold_refinement.py`.
- Adds `scripts/run_threshold_refinement.sh`.
- Uses the v4.77 best damped candidate and conservative CL/gain nudges.
- Default amplitude ladder: 50,40,35,30,25,20,15,10 counts.
- More repeats near the 40-count threshold.
- Keeps hard safety aborts for Pico latch, ViX fault line, encoder-invalid change, operator stop, and excessive movement.

Purpose: validate 400 nm repeatability and determine whether 300/250/200 nm is reachable before any renewed 100 nm proof attempt.

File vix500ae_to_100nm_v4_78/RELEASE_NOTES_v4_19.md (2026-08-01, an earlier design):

# v4.19 comprehensive adaptive commissioning revision

## Why this revision exists

The v4.18 Stage 3 run did not lose STEP pulses. It failed before issuing the
250-count move because the baseline target estimator required five nearly
stationary `PA -> PE -> PA` brackets and obtained four. The field sequence moved
from `PA=+189` to approximately `PA=-136` counts while the reconstructed target
remained clustered around zero. That was a slow enabled settling response from
the conservative Stage 2 gain, not bad encoder data or a target-scale failure.

v4.19 addresses the entire downstream design mismatch rather than adding
another one-line exception.

## Comprehensive Stage 3

Stage 3 now performs, in one attended run:

1. A complete bounded zero-target GP/GV hold sweep at `CL=2%`.
2. Selection of the quietest candidate that holds with `|PE| <= 10` counts.
3. A small sign probe that independently determines `ENCSIGN` and `DIRINV`.
4. Robust STEP/count validation using time-interpolated `PA -> PE -> PA`
   brackets.
5. `+250, -250, +250` verification, automatically retried at slower STEP rates
   only when needed.
6. Full `+1000` and `-1000` adaptive-settling tests.

The gain sweep is bounded to predefined zero-integral candidates from
`GP/GV=2/1` through `64/64`. `GF=GI=FT=0`, `PC=100%`, `TL=5000`, and
`CL=2%` remain enforced. Any fault, Limit+, impossible encoder transition,
I2t indication, watchdog loss, or 20 micrometre hold displacement stops the
sweep immediately.

## Target estimator

The ViX500AE does not reliably return `R(PT)`. v4.19 uses the field-observed
relationship `PE = PA - PT`, but no longer requires the stage to be stationary.

For every bracket it timestamps `PA1`, `PE`, and `PA2`, interpolates PA to the
PE timestamp, and computes the target. Seven estimates are robustly clustered;
outliers are rejected and the measured estimator uncertainty becomes the scale
tolerance, bounded to 5-12 counts.

This directly covers both prior failures:

- asynchronous PA/PE values cannot create a false 234/250 result;
- slow baseline movement cannot fail merely because only four stationary
  brackets were collected.

## Stages 4-7 audited in advance

All commanded ABBA legs now use adaptive endpoint settling. Fixed sleeps are
no longer used as evidence that a move settled. The gate checks:

- corrected Pico endpoint error;
- endpoint span over a recent time window;
- ViX fault output and DF status;
- Limit+;
- impossible encoder transitions;
- I2t;
- verified energisation.

The first-block trace period is planned from the worst-case move and adaptive
settling duration, preventing a later 4096-sample trace overflow. Shams use a
matched dwell based on recent real settling times. Evidence now records every
leg's settle time, goal, tail span, and pass/fail state.

## Firmware and saved state

This is a host-side commissioning revision. Pico firmware remains
`vix-base-pico2-v2.7`, protocol 5. No reflash is required when v2.6 is already
installed.

State schema remains 10, but the fingerprint now includes the v4.19
commissioning-policy ID. v4.18 and v2.5 legacy states are migrated explicitly:
Stages 0-2 are preserved, while Stage 3 and all downstream pass flags, signs,
motion gains, and 100 nm metrics are invalidated and recalculated.

## Additional release audit corrections

- The first real ABBA block always precedes shams, so trace capture is
  deterministic and sham timing has measured settling data available.
- Sham dwell follows the recent real-leg settling median up to the same
  amplitude-specific endpoint budget; it is no longer truncated at 3 seconds.
- Current instructions consistently require Pico v2.6/protocol 5.
- The Stage 3 prompt reports the actual 20 µm zero-target hold cutoff and 50 µm
  probe following-error window.

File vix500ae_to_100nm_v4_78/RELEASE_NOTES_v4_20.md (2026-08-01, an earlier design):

# v4.20 Stage 2/3 long-hold and local-zero hardening

## Why this revision exists

The 2026-07-29 Stage 3 evidence showed that the previously saved Stage 2 gain
seed `GF0_GI0_GP2_GV1_FT0` could pass the short ladder but then fail the longer
Stage 3 hold. During that failed hold the carriage drifted on the order of
100-200 encoder counts, which is already much larger than the 10-count/100 nm
final goal. After the failed hold, the next local-zero attempt reported
`ViX PA=0`, `Pico=0`, but `ViX PE=-195`, proving the host must not assume the
ViX target/error registers are clean merely because PA was set to zero.

## Host changes

- Bumped host commissioning state schema to 11 and policy fingerprint to
  `comprehensive_adaptive_v4_20`.
- Migrates v4.19/v4.18/v2.5 states by preserving only Stages 0-1. Stage 2 and
  downstream are invalidated so the gain seed is retested under the new long
  quiet-hold rule.
- Replaced the single `W(PA,0)` local-zero assumption with a verified
  PA/PT/PF/PE + Pico encoder/command/following-error transaction.
- Uses bounded recovery sequences while OFF: `W(PA,0)`, then
  `W(PE,0); W(PT,0); W(PA,0)`, then
  `W(PE,0); W(PT,0); W(PF,0); W(PA,0)` if needed.
- Stage 2 now uses the same long-hold PE/tail-span/tail-slope rule that gates
  Stage 3 motion.
- Stage 3 no longer escalates to higher stiffness after an unsettled hold. It
  revalidates only the conservative candidates up to the Stage 2 seed, stops at
  the first unsettled candidate, and performs no sign/scale moves unless a quiet
  hold exists.

## Operator impact

After installing v4.20, restart from Stage 2. Existing Stage 0/1 proof may be
preserved by the migration, but old Stage 2/3 pass flags are intentionally
removed.

Recommended command:

```bash
python3 host/vix100nm_commission.py \
  --stage 2 \
  --vix-port /dev/ttyUSB0 \
  --pico-port /dev/ttyACM0 \
  --bench-no-estop
```

Do not rerun v4.19 Stage 3. The v4.20 host will refuse to proceed from the old
gain seed and dirty reference-state assumptions.

## Validation

`./scripts/run_offline_checks.sh` passes after updating checksums.

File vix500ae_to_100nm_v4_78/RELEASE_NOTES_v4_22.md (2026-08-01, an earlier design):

# v4.22 release notes

Purpose: fix the Stage 2 v4.21 field result where `GP0.25/GV0.25` held safely but drifted about 11 um, then the host stopped before trying the rest of the already-bounded gain ladder.

Changes:

- Stage 2 now distinguishes **too-soft/unsettled but safe** from a true safety abort.
- A safe, unsettled candidate no longer stops the Stage 2 sweep before higher bounded candidates.
- The sweep starts at `CL=2%`; if all bounded gains are still too soft, it adaptively repeats at `CL=3%` and then `CL=5%`.
- Later stages reuse the Stage 2 selected current clamp instead of assuming `CL=2%`.
- Stage 3 still refuses to go beyond the Stage 2-qualified seed during sign/scale work.
- v4.21 state migrates by preserving Stages 0-1 and invalidating Stage 2+.

Safety gates kept:

- ViX DF abort
- Pico fault/limit/E-stop abort
- encoder-invalid abort
- I2t abort
- watchdog abort
- dirty local-zero abort
- 20 um Stage 2 hold displacement gate
- 50/100 um later-stage motion guard windows

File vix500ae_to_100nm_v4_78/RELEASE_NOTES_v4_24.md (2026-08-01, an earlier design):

# v4.24 release notes

## Field evidence that triggered this patch

Two v4.23 Stage 2 runs exposed two separate, recoverable cases after the gain ladder started working:

1. The long-hold ladder found a real 10-count-class candidate at CL=2%:
   `GAINS(0,0.1,2,1,0)` passed with `PE=-6 counts` and `tail span=2 counts`.
2. The selected-gain trace confirmation then hit the same stale ViX PE local-zero state that candidate preparation already knew how to recover from. The confirmation path still used the old direct `prepare_pico_for_enable()` call, so it aborted with `PE=-13` instead of using the bounded OFF+Z reset wrapper.
3. A second run aborted because the stage moved only about 6-8 counts during the single 0.25 s local-zero quiet check. That is 60-80 nm at this encoder scale and should be treated as a short relaxation window to wait through, not as immediate failure, unless it keeps creeping or exceeds the bounded total drift gate.

## Host changes

- Stage 2 selected-gain confirmation now uses the same bounded stale-PE reset wrapper as the candidate loop:
  - OFF
  - Pico disable/disarm/clear
  - ViX Z reset/restore
  - re-apply volatile MP/gain/CL/TL setup
  - re-apply Pico policy
  - retry local-zero once
- Local-zero preparation now waits for one quiet 0.25 s window, up to 2.0 s total, instead of aborting on a single 6-8 count relaxation interval.
- Continuous creep is still rejected: total drift beyond the bounded local-zero allowance or no quiet window by the deadline aborts.
- Stage 2+ is invalidated on migration from v4.23 because the selected-gain confirmation and local-zero settle rules changed.

## Expected behavior

A rerun of Stage 2 should preserve Stages 0-1, retest the ladder, select the observed stable seed if it repeats, then proceed into the selected-gain confirmation instead of aborting on stale PE or a one-window nanometer-scale relaxation.

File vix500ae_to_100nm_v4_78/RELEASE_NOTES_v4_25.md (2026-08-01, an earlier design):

# v4.25

State-recovery patch after accidental older-bundle execution.

- Adds `--recover-stage2-from-evidence` to rehydrate a validated v4.24+ Stage 2 PASS from `gain_ladder.json` or the evidence zip/directory.
- Preserves v4.24 Stage 2 state during v4.25 migration because the powered tuning policy is unchanged.
- Auto-repairs a missing Stage 2 pass flag if a measured selected gain/current seed is still present in the state file.
- Keeps Stage 3+ invalidated after recovery; Stage 3 must still be run from the latest bundle.

## v4.26 note
Stage 3 revalidates the proven Stage 2 gain seed first before testing nearby alternatives.

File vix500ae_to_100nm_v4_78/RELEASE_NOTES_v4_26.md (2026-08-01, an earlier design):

# v4.26 release notes

Purpose: fix Stage 3 after a validated v4.24/v4.25 Stage 2 hold pass.

## Field failure addressed

v4.25 rehydrated the validated Stage 2 seed correctly, but Stage 3 revalidated from the soft beginning of the ladder (`GF0 GI0 GP0.25 GV0.25 FT0`) and aborted as soon as that known-too-soft candidate drifted. It therefore never reached the measured Stage 2 pass seed (`GF0 GI0.1 GP2 GV1 FT0`, `CL=2%`).

## Changes

- Stage 3 now revalidates the selected Stage 2 seed first.
- If the seed revalidates, Stage 3 may score bounded nearby comparison candidates.
- A softer post-seed comparison candidate becoming unsettled no longer invalidates the already-revalidated seed.
- v4.25 and v4.24 states preserve Stage 2 during migration.
- Stages 3+ remain invalidated on migration.

## Safety behavior unchanged

Stage 3 still aborts before sign/scale motion if the selected Stage 2 seed itself is rejected, unsettled, faults, exceeds the local motion gate, trips Pico following-error/watchdog/limit checks, or leaves unrecoverable dirty zero state.

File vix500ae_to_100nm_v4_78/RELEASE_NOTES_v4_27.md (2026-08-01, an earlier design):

# v4.27 release notes

- Fixes v4.26 schema migration: accepts schema 16/17 state files created by v4.25/v4.26 after validated Stage-2 evidence rehydration.
- Preserves validated Stage 2 selected hold seed and current clamp while invalidating only Stage 3+ downstream results.
- Keeps v4.26 Stage 3 behavior: revalidate the selected Stage-2 seed before any softer/stiffer comparison candidates.
- Offline checks pass.

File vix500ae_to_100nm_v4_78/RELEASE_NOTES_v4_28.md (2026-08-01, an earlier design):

# v4.28 release notes

## Purpose

Reduce Stage 3 back-and-forth after the first validated 100 nm-class Stage 2 hold seed.

## Field evidence addressed

- Stage 2 v4.24 selected `CL=2%`, `GAINS(0,0.1,2,1,0)` with a 10-count-class hold.
- Stage 3 v4.27 revalidated the correct seed, but rejected it when ViX serial polling left the final time-based tail under-sampled: `PE=3 counts`, `tail span=1000000000` sentinel.

## Changes

- Stage 3 is now a seed-revalidation and direction/scale gate, not a second gain-tuning ladder.
- Stage 3 revalidates only the measured Stage 2 seed, avoiding optional neighbor comparisons that could create unnecessary aborts.
- Added a sparse-tail-safe Pico-only confirmation window while the drive is still enabled. If the ViX PE is already within the 10-count goal but the serial-poll tail is under-sampled, the script captures a short high-rate Pico tail before rejecting the seed.
- Direction probes now use the same bounded stale-PE local-zero reset recovery as the hold ladder.
- v4.28 migrates v4.27 state and preserves the validated Stage 2 seed.
- Added offline regressions for sparse-tail seed revalidation and Stage 3 seed-only candidate ordering.

## Still intentionally blocked

- Real ViX DF faults.
- Pico latches, Limit+, encoder-invalid transitions, watchdog loss, or fault-output assertion.
- Repeated dirty local-zero after bounded OFF+Z recovery.
- Actual excessive movement during hold or direction probes.

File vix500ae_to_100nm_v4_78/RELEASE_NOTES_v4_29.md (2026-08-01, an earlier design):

# v4.29 release notes

Fixes Stage 3 direction/scale coordinate handling after v4.28 proved the selected Stage 2 gain seed but aborted when Parker ViX PA/PT used the opposite sign from the Pico command coordinate.

Key changes:

- Keeps the Pico encoder sign aligned to the Pico MOVE command coordinate, because that is the coordinate used by the firmware following-error safety latch.
- Adds `vix_axis_sign` so raw ViX PA/PT deltas can be transformed into the Pico command coordinate for evidence comparisons.
- Stage 3 no longer flips ENCSIGN merely to make Pico encoder response match raw Parker PA polarity.
- Direction/scale, coarse, fine, final 100 nm, and experimental 20/30 nm summaries now compare Pico and ViX after applying `vix_axis_sign`.
- Preserves the proven Stage 2 seed path and remains bounded by the same CL, TL, fault, limit, I2t, watchdog, and encoder-invalid gates.

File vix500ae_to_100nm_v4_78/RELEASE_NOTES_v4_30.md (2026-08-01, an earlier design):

# v4.30 release notes

Purpose: make Stage 3 stop failing one probe at a time when bidirectional direction evidence is inconsistent.

Changes:

- Stage 3 no longer aborts immediately on the first opposite corrected encoder response during +250/-250/+250 calibration.
- It completes a bounded bidirectional calibration matrix across the inferred DIRINV setting, alternate DIRINV, available ViX comparison signs, and fallback step rates.
- It writes `direction_scale_rate_diagnostics.json` during the matrix so partial results are preserved even if a later trial fails.
- It writes `direction_failure_diagnosis.json` with an explicit same-direction symptom detector. If both positive and negative commands produce the same encoder direction across DIRINV trials, the remaining issue is likely DIR signal wiring/line-driver/input behavior rather than servo hold tuning.
- v4.30 migrates v4.28/v4.29 state without erasing a validated Stage 2 hold seed.

Known state from the field before this patch:

- Stage 2 hold seed is good: CL=2%, GAINS(0,0.1,2,1,0).
- Stage 3 hold revalidation is good: PE near 0 to -5 counts, tail span about 1 count.
- Current blocker is bidirectional STEP/DIR proof, specifically the negative 250-count command producing positive encoder response in v4.29.

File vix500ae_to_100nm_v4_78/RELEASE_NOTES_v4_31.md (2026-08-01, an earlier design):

# v4.31 release notes

Purpose: reduce Stage 3 back-and-forth by fixing the OFF-state local-zero settle gate seen on 2026-07-30.

Changes:
- Treat Pico raw encoder as the primary physical stationarity witness during OFF-state local-zero preparation.
- Treat ViX PA movement during OFF+Z/reset reference refresh as advisory when Pico raw is quiet and ViX PA delta is bounded.
- Preserve the PA/PT/PF/PE zero transaction immediately after the advisory settle window, so stale ViX references are still cleaned before enabling.
- Migrate v4.30 state without erasing validated Stage 2 evidence/seed.
- Keep the v4.30 bidirectional direction diagnostic matrix for DIRINV/STEP-DIR investigation.

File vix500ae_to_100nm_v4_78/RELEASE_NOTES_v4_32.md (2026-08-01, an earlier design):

# v4.32 release notes

Intent: harden Stage 3 so non-hard diagnostic failures do not create a one-patch-per-abort loop.

Changes:

- Preserves v4.31/v4.30/v4.29/v4.28/v4.27/v4.26/v4.25/v4.24 Stage-2 evidence/state where the 100 nm-class hold seed is already validated.
- Keeps hard stops for real unsafe conditions: ViX drive faults, limits, E-stop/watchdog, I2t, encoder-invalid/runaway, unsafe cleanup, and serial port permission/open failures.
- Classifies polarity, endpoint settling, ViX/Pico disagreement, target-scale, and local-zero ambiguity as bounded diagnostic failures when safe, records them, and continues the Stage-3 bidirectional matrix instead of aborting immediately.
- Makes direction_scale_rate_diagnostics.json and direction_failure_diagnosis.json more likely to contain the full +250/-250/+250 matrix rather than only the first failing row.
- Adds an offline regression for Stage-3 diagnostic soft-fail classification.

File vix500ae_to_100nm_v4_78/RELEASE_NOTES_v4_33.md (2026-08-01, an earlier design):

# v4.33 release notes

Intent: reduce one-abort-per-transient behavior while keeping encoder safety hard.

Changes:

- Adds one bounded ENCODER_INVALID recovery during the X4-enable/ViX-ON handshake.
- If the first ENCODER_INVALID happens, the host disables X4, sends OFF, clears Pico latch/diagnostics, verifies the encoder-invalid counter stays quiet while disabled, then retries energising once.
- If ENCODER_INVALID repeats, the script stops with a hardware-oriented diagnosis instead of needing another patch.
- Keeps ENCODER_INVALID as a hard safety gate for actual motion and repeated enable-time failures. 100 nm movement is not trustworthy if the quadrature stream is producing impossible transitions while enabled.
- Keeps the v4.32 Stage-3 diagnostic matrix behavior for non-hard direction/polarity/settling cases.

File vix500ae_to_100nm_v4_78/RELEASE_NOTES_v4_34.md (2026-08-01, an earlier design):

# v4.34

Hardens Stage 3 energize retry recovery.

- Re-arms the Pico before retrying ENABLE after bounded ENCODER_INVALID cleanup.
- Clears host-generated USER_ABORT latch before a retry, but refuses to enable through any real safety latch.
- Re-zeros Pico local command/encoder coordinates after disabled recovery cleanup when needed.
- Keeps ENCODER_INVALID repeated-latch behavior as a hard stop for encoder signal-integrity diagnosis.

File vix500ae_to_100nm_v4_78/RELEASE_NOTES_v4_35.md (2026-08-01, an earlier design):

# v4.35 release notes

## Intent

Harden Stage 3 against host-side Pico ZERO ordering bugs exposed by the v4.34 direction-scale run.

## Changes

- Adds `safe_pico_zero()`, a single transaction for every host-side Pico zero:
  1. abort only if motion is active,
  2. force `ENABLE 0`,
  3. force `DISARM`,
  4. clear only host-generated `USER_ABORT`,
  5. then issue `ZERO` and verify it stuck.
- Replaces all host-side direct `ZERO` calls with `safe_pico_zero()` in guarded recovery, local-zero transactions, energize retry cleanup, and encoder-invalid retry cleanup.
- Preserves Stage 2 when migrating from v4.32-v4.34 policy state, but still invalidates Stage 3+.
- Adds an offline regression for the exact firmware rule: Pico rejects `ZERO` unless disabled and disarmed.

## Safety behavior

This does not bypass hardware latches. Repeated `ENCODER_INVALID`, active limit, fault input, unsafe E-stop state, ViX DF, runaway/following-error, or a Pico latch other than host-generated `USER_ABORT` still stops the test.

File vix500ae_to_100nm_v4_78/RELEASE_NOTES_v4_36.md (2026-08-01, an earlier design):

# v4.36 fast Stage-3 resume

Adds `--stage3-fast-resume` for the validated ViX500AE/MX80L setup. The fast path rehydrates the v4.24+ Stage-2 gain seed, skips the long gain ladder and sign rediscovery, performs one short hold spot-check, and runs a direct +250/-250/+250 bidirectional STEP/DIR proof at 250 cps with one 100 cps fallback.

Known validated assumptions from prior evidence:
- `CL=2%`
- `GAINS(0,0.1,2,1,0)`
- `ENCSIGN=+1`
- `DIRINV=0`
- raw ViX PA/PT comparison sign `-1`

It also retries incomplete ViX STATUS identity reads during fast preflight, while preserving hard stops for faults, limits, unsafe inputs, repeated encoder-invalid, I2t, runaway, and watchdog failures.

Convenience wrapper:

```bash
./scripts/run_stage_3_fast_resume.sh
```

or pass a different Stage-2 evidence zip as the first argument.

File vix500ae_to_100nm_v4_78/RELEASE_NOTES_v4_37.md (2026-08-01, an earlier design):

# v4.37 post-DIR-wiring fast resume

Purpose: after the AM26LV31 DIR wiring fix, skip the old sign discovery and use the coordinate frame shown by the latest v4.36 evidence.

Changes:
- Fast Stage 3 uses ENCSIGN=-1, DIRINV=0, ViXsign=+1.
- Keeps the validated Stage 2 seed: CL=2%, GAINS(0,0.1,2,1,0).
- Continues to require a short hold spot-check and +250/-250/+250 bidirectional STEP/DIR proof before Stage 4.
- Does not hide repeated ENCODER_INVALID or real DF/limit/fault conditions.

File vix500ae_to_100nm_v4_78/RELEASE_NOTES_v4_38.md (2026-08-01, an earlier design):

# v4.38 Release Notes — coarse endpoint IW/current fallback

Purpose: after the corrected STEP/DIR wiring and a passing fast Stage 3, Stage 4 reached the 100 um ABBA ladder but failed endpoint settling on block 1 leg 3 with a quiet residual around 173 counts. That pattern is not a direction failure; it is a post-move endpoint capture issue.

Changes:

- Adds a temporary motion integral-window policy for coarse/fine/validation moves: `W(IM,1)` and `W(IW,1000)`.
- Keeps the proven gain seed `GAINS(0,0.1,2,1,0)` unless earlier stages select something else.
- Stage 4 first tries the 100 um ABBA block using the selected CL, then bounded fallbacks `CL=3%` and `CL=5%` if needed.
- Records `coarse_10000_candidate_attempts.json` so current-limit versus endpoint-settle behavior is distinguishable.
- Stores `motion_cl_percent` and `motion_iw_counts` on Stage 4 pass; Stages 5-7 use these motion settings.
- No settings are saved to the ViX drive.

Run Stage 4 from this folder after Stage 3 has passed.

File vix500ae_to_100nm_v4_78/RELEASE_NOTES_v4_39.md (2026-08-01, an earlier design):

# v4.39

Stage-4 state migration hotfix.

- Accepts schema 26/27 state from v4.36/v4.37/v4.38.
- Preserves a validated v4.36/v4.37 Stage-3 DIR proof when entering Stage 4.
- Keeps Stage-4 coarse endpoint policy from v4.38: IM=1, IW=1000, CL fallback 2/3/5%.
- Prevents unnecessary reruns of Stage 2/3 after the wiring-corrected Stage-3 pass.

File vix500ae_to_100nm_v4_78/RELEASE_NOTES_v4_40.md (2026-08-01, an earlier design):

# v4.40

- Stage 4 now clears stale ViX PE/PT state between bounded current-clamp attempts.
- Stage 4 uses the same OFF+Z reset/local-zero recovery used by Stage 3 before each coarse 100 um candidate.
- This lets CL=3% and CL=5% actually run after a CL=2% endpoint-shortfall, instead of being blocked by stale PE left by the failed leg.
- Preserves v4.37/v4.39 Stage 2+3 state.

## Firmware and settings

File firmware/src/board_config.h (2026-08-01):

#ifndef VIX_BASE_PICO2_BOARD_CONFIG_H
#define VIX_BASE_PICO2_BOARD_CONFIG_H

/*
 * Conservative commissioning pin map.
 * Change only with the drive disabled and update WIRING.md at the same time.
 */
#define FW_VERSION "vix-base-pico2-v2.7"
#define PROTOCOL_REVISION 5
#define COUNTS_PER_MM 100000

#define PIN_STEP          2u
#define PIN_DIR           3u
#define PIN_ENCODER_A     4u
#define PIN_ENCODER_B     5u
#define PIN_ENCODER_Z     6u
#define PIN_LIMIT_POS     7u
#define PIN_LIMIT_NEG     8u
#define PIN_HOME          9u
#define PIN_VIX_FAULT    10u
#define PIN_DRIVE_ENABLE 11u
#define PIN_ESTOP_AUX    12u

/* These defaults cannot arm motion until CONFIRM_INPUTS is explicitly set. */
#define DEFAULT_LIMIT_POS_ACTIVE_LEVEL 1
#define DEFAULT_LIMIT_NEG_ACTIVE_LEVEL 0
#define DEFAULT_HOME_ACTIVE_LEVEL      1
#define DEFAULT_Z_ACTIVE_LEVEL         1
#define DEFAULT_FAULT_ACTIVE_LEVEL     1
#define DEFAULT_HAS_LIMIT_NEG          false

/* X5 limit/home safety inputs are open-collector/noisy in this setup.
 * Require this many consecutive 10 kHz firmware samples before an active
 * level is treated as true. 5 samples = about 0.5 ms. Inactive clears
 * immediately so a released switch is not artificially held active. */
#define X5_INPUT_DEBOUNCE_SAMPLES      5u

#define DEFAULT_ENCODER_SIGN           1
#define DEFAULT_COMMAND_DIR_INVERTED   false
#define DEFAULT_REQUIRE_ESTOP_AUX      true

/* 10 nm/count defaults. The host rewrites these volatile limits each session. */
#define DEFAULT_SOFT_MIN_COUNTS       (-200000)
#define DEFAULT_SOFT_MAX_COUNTS        200000
#define DEFAULT_FOLLOWING_ABORT_COUNTS 5000
#define DEFAULT_HOST_WATCHDOG_MS       750u

#define TRACE_MAX_SAMPLES              4096u
#define TRACE_DEFAULT_PERIOD_US        1000u

/* Guarded stale-fault recovery pulse. The host must also set zero gains and
 * CL=1% before requesting this. Firmware independently bounds both time and
 * encoder displacement while temporarily ignoring only the already-active
 * ViX fault input. */
#define RECOVERY_MIN_MS                 100u
#define RECOVERY_MAX_MS                2000u
#define RECOVERY_MAX_DELTA_COUNTS       5000u

/* Deliberately low commissioning limits. */
#define MIN_STEP_RATE_COUNTS_S 100u
#define MAX_STEP_RATE_COUNTS_S 20000u
#define MAX_ACCEL_COUNTS_S2    1000000u
#define STEP_SEGMENT_COUNTS    16u

#endif

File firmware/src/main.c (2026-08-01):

/*
 * ViX AE/AH base drive + MX80L + Raspberry Pi Pico 2 supervisory controller
 * -------------------------------------------------------------------
 *
 * INTENT
 *   Generate deterministic differential step/direction commands through an
 *   AM26LV31, independently count the ViX encoder-copy through an AM26LV32,
 *   monitor the MX80L limit/home signals and ViX fault output, and expose a
 *   conservative USB serial control protocol for commissioning and nanostep
 *   experiments.
 *
 * SAFETY BOUNDARY
 *   The ViX AE/AH base drive remains the high-bandwidth servo. This firmware does not configure
 *   MOTOR, feedback phasing, PIVF gains, or non-volatile memory. It boots
 *   disarmed and de-energised. A hardware E-stop/HV disconnect is still
 *   mandatory. The current stage has no working negative limit, so the default
 *   policy is a +/-2 mm software window around a manually centred temporary
 *   zero. No automatic homing or full-travel search is implemented.
 */

#include <inttypes.h>
#include <stdbool.h>
#include <stdint.h>
#include <stdio.h>
#include <stdlib.h>
#include <string.h>

#include "hardware/clocks.h"
#include "hardware/gpio.h"
#include "hardware/irq.h"
#include "hardware/pio.h"
#include "pico/multicore.h"
#include "pico/stdlib.h"
#include "pico/util/queue.h"

#include "board_config.h"
#include "stepgen.pio.h"
#include "quadrature_encoder.pio.h"

#define LINE_BUFFER_SIZE 192u

typedef enum {
    MOTION_IDLE = 0,
    MOTION_MOVING = 1,
    MOTION_ABORTED = 2
} motion_state_t;

typedef enum {
    LATCH_NONE = 0,
    LATCH_ESTOP,
    LATCH_VIX_FAULT,
    LATCH_LIMIT_POS,
    LATCH_LIMIT_NEG,
    LATCH_FOLLOWING_ERROR,
    LATCH_HOST_WATCHDOG,
    LATCH_ENCODER_INVALID,
    LATCH_USER_ABORT,
    LATCH_RECOVERY_TIMEOUT,
    LATCH_INTERNAL
} latch_code_t;

typedef struct {
    int limit_pos_active_level;
    int limit_neg_active_level;
    int home_active_level;
    int z_active_level;
    int fault_active_level;
    bool has_limit_neg;
    int encoder_sign;
    bool command_dir_inverted;
    bool require_estop_aux;
    int32_t soft_min_counts;
    int32_t soft_max_counts;
    int32_t following_abort_counts;
    uint32_t host_watchdog_ms;
    bool inputs_confirmed;
} runtime_config_t;

typedef struct {
    int32_t delta_counts;
    uint32_t max_rate_counts_s;
    uint32_t accel_counts_s2;
    uint32_t move_id;
    uint32_t abort_epoch;
} move_request_t;

typedef struct {
    uint32_t t_us;
    int32_t encoder_position;
    int32_t command_position;
    int32_t following_error;
    uint32_t encoder_invalid;
    uint32_t flags;
} trace_sample_t;

#define TRACE_FLAG_ENABLED      (1u << 0)
#define TRACE_FLAG_ARMED        (1u << 1)
#define TRACE_FLAG_MOVING       (1u << 2)
#define TRACE_FLAG_LIMIT_POS    (1u << 3)
#define TRACE_FLAG_LIMIT_NEG    (1u << 4)
#define TRACE_FLAG_HOME         (1u << 5)
#define TRACE_FLAG_FAULT        (1u << 6)
#define TRACE_FLAG_ESTOP_SAFE   (1u << 7)
#define TRACE_FLAG_LATCHED      (1u << 8)
#define TRACE_FLAG_RECOVERY     (1u << 9)

static runtime_config_t g_cfg = {
    .limit_pos_active_level = DEFAULT_LIMIT_POS_ACTIVE_LEVEL,
    .limit_neg_active_level = DEFAULT_LIMIT_NEG_ACTIVE_LEVEL,
    .home_active_level = DEFAULT_HOME_ACTIVE_LEVEL,
    .z_active_level = DEFAULT_Z_ACTIVE_LEVEL,
    .fault_active_level = DEFAULT_FAULT_ACTIVE_LEVEL,
    .has_limit_neg = DEFAULT_HAS_LIMIT_NEG,
    .encoder_sign = DEFAULT_ENCODER_SIGN,
    .command_dir_inverted = DEFAULT_COMMAND_DIR_INVERTED,
    .require_estop_aux = DEFAULT_REQUIRE_ESTOP_AUX,
    .soft_min_counts = DEFAULT_SOFT_MIN_COUNTS,
    .soft_max_counts = DEFAULT_SOFT_MAX_COUNTS,
    .following_abort_counts = DEFAULT_FOLLOWING_ABORT_COUNTS,
    .host_watchdog_ms = DEFAULT_HOST_WATCHDOG_MS,
    .inputs_confirmed = false,
};

static queue_t g_move_queue;
static PIO g_step_pio = pio0;
static uint g_step_sm = 0;
static uint g_step_offset = 0;

/* PIO1 is dedicated to the high-rate quadrature decoder. The PIO state
 * machine counts continuously without CPU intervention. Core 0 refreshes this
 * cached count at 10 kHz; core 1 only reads the cache for following-error
 * protection, so the RX FIFO is never drained concurrently by both cores. */
static PIO g_encoder_pio = pio1;
static uint g_encoder_sm = 0;
static uint g_encoder_offset = 0;
static volatile int32_t g_encoder_raw = 0;
static volatile uint32_t g_encoder_invalid_transitions = 0;
static volatile uint32_t g_z_edges = 0;
static volatile int32_t g_last_z_raw = 0;

static trace_sample_t g_trace[TRACE_MAX_SAMPLES];
static volatile bool g_trace_active = false;
static volatile bool g_trace_full = false;
static volatile uint32_t g_trace_count = 0;
static volatile uint32_t g_trace_capacity = TRACE_MAX_SAMPLES;
static volatile uint32_t g_trace_period_us = TRACE_DEFAULT_PERIOD_US;
static volatile uint64_t g_trace_start_us = 0;
static volatile uint64_t g_trace_next_us = 0;

static volatile uint64_t g_last_heartbeat_us = 0;

/* X5 limit/home input guard. The MX80L limit/home lines are open-collector and
 * have shown single-sample phantom triggers on this bench. Treat an X5 safety
 * signal as active only after X5_INPUT_DEBOUNCE_SAMPLES consecutive firmware
 * samples at the active level. Samples are taken in the 10 kHz main-loop input
 * refresh. Inactive clears immediately; this is intentional so a released limit
 * is not artificially stretched. */
static volatile uint8_t g_limit_pos_active_streak = 0;
static volatile uint8_t g_limit_neg_active_streak = 0;
static volatile uint8_t g_home_active_streak = 0;
static volatile bool g_limit_pos_debounced = false;
static volatile bool g_limit_neg_debounced = false;
static volatile bool g_home_debounced = false;

static volatile int32_t g_encoder_zero_raw = 0;
static volatile int32_t g_command_position = 0;
static volatile bool g_zeroed = false;
static volatile bool g_armed = false;
static volatile bool g_drive_enabled = false;
static volatile bool g_abort_requested = false;
/* Incremented on every stop/abort request. Queued moves carry the epoch at
 * acceptance so an old queued request can never run after re-arming. */
static volatile uint32_t g_abort_epoch = 0;
static volatile bool g_safety_latched = false;
static volatile latch_code_t g_latch_code = LATCH_NONE;
static volatile motion_state_t g_motion_state = MOTION_IDLE;
static volatile int g_motion_direction = 0;
static volatile uint32_t g_active_move_id = 0;
static volatile uint32_t g_completed_move_id = 0;

/* Dedicated, internally timed stale-fault recovery gate. This is deliberately
 * separate from normal ARM/ENABLE operation: it can assert GP11 while the ViX
 * fault input is already active, but only for a bounded interval and with an
 * independent raw-encoder displacement limit. */
static volatile bool g_recovery_active = false;
static volatile uint64_t g_recovery_started_us = 0;
static volatile uint64_t g_recovery_deadline_us = 0;
static volatile int32_t g_recovery_encoder_start_raw = 0;
static volatile uint32_t g_recovery_invalid_start = 0;
static volatile uint32_t g_recovery_max_abs_delta = 0;
static volatile uint32_t g_recovery_elapsed_ms = 0;
static volatile bool g_recovery_timed_out = false;
static volatile bool g_recovery_fault_cleared = false;
static volatile bool g_recovery_fault_reasserted = false;

static void latch_and_disable(latch_code_t code);
static inline uint32_t magnitude_i32(int32_t value);
static inline uint32_t magnitude_following_error(void);
static void recovery_stop(bool timed_out);

static const char *motion_state_name(motion_state_t state) {
    switch (state) {
        case MOTION_IDLE: return "IDLE";
        case MOTION_MOVING: return "MOVING";
        case MOTION_ABORTED: return "ABORTED";
        default: return "UNKNOWN";
    }
}

static inline void refresh_encoder_count(void) {
    g_encoder_raw = quadrature_encoder_get_count(g_encoder_pio, g_encoder_sm);
}

static const char *latch_name(latch_code_t code) {
    switch (code) {
        case LATCH_NONE: return "NONE";
        case LATCH_ESTOP: return "ESTOP";
        case LATCH_VIX_FAULT: return "VIX_FAULT";
        case LATCH_LIMIT_POS: return "LIMIT_POS";
        case LATCH_LIMIT_NEG: return "LIMIT_NEG";
        case LATCH_FOLLOWING_ERROR: return "FOLLOWING_ERROR";
        case LATCH_HOST_WATCHDOG: return "HOST_WATCHDOG";
        case LATCH_ENCODER_INVALID: return "ENCODER_INVALID";
        case LATCH_USER_ABORT: return "USER_ABORT";
        case LATCH_RECOVERY_TIMEOUT: return "RECOVERY_TIMEOUT";
        case LATCH_INTERNAL: return "INTERNAL";
        default: return "UNKNOWN";
    }
}

static inline bool raw_level(uint pin) {
    return gpio_get(pin) != 0;
}

static inline bool active_level(uint pin, int active) {
    return raw_level(pin) == (active != 0);
}

static inline bool limit_pos_active_raw(void) {
    return active_level(PIN_LIMIT_POS, g_cfg.limit_pos_active_level);
}

static inline bool limit_neg_active_raw(void) {
    return g_cfg.has_limit_neg &&
           active_level(PIN_LIMIT_NEG, g_cfg.limit_neg_active_level);
}

static inline bool home_active_raw(void) {
    return active_level(PIN_HOME, g_cfg.home_active_level);
}

static inline void update_one_x5_debounce(bool raw_active,
                                          volatile uint8_t *streak,
                                          volatile bool *debounced) {
    if (raw_active) {
        if (*streak < X5_INPUT_DEBOUNCE_SAMPLES) {
            *streak = (uint8_t)(*streak + 1u);
        }
        if (*streak >= X5_INPUT_DEBOUNCE_SAMPLES) {
            *debounced = true;
        }
    } else {
        *streak = 0u;
        *debounced = false;
    }
}

static inline void update_x5_debounced_inputs(void) {
    update_one_x5_debounce(
        limit_pos_active_raw(),
        &g_limit_pos_active_streak,
        &g_limit_pos_debounced
    );
    update_one_x5_debounce(
        limit_neg_active_raw(),
        &g_limit_neg_active_streak,
        &g_limit_neg_debounced
    );
    update_one_x5_debounce(
        home_active_raw(),
        &g_home_active_streak,
        &g_home_debounced
    );
}

static inline bool limit_pos_active(void) {
    return g_limit_pos_debounced;
}

static inline bool limit_neg_active(void) {
    return g_cfg.has_limit_neg && g_limit_neg_debounced;
}

static inline bool home_active(void) {
    return g_home_debounced;
}

static inline bool z_active(void) {
    return active_level(PIN_ENCODER_Z, g_cfg.z_active_level);
}

static inline bool vix_fault_active(void) {
    return active_level(PIN_VIX_FAULT, g_cfg.fault_active_level);
}

static inline bool estop_safe(void) {
    if (!g_cfg.require_estop_aux) {
        return true;
    }
    /* NC auxiliary contact: closed -> raw low -> safe. */
    return !raw_level(PIN_ESTOP_AUX);
}

static inline int32_t encoder_position(void) {
    const int32_t delta = g_encoder_raw - g_encoder_zero_raw;
    return (g_cfg.encoder_sign >= 0) ? delta : -delta;
}

static inline int32_t following_error(void) {
    return g_command_position - encoder_position();
}

static uint32_t trace_flags(void) {
    uint32_t flags = 0u;
    if (g_drive_enabled) flags |= TRACE_FLAG_ENABLED;
    if (g_armed) flags |= TRACE_FLAG_ARMED;
    if (g_motion_state == MOTION_MOVING) flags |= TRACE_FLAG_MOVING;
    if (limit_pos_active()) flags |= TRACE_FLAG_LIMIT_POS;
    if (limit_neg_active()) flags |= TRACE_FLAG_LIMIT_NEG;
    if (home_active()) flags |= TRACE_FLAG_HOME;
    if (vix_fault_active()) flags |= TRACE_FLAG_FAULT;
    if (estop_safe()) flags |= TRACE_FLAG_ESTOP_SAFE;
    if (g_safety_latched) flags |= TRACE_FLAG_LATCHED;
    if (g_recovery_active) flags |= TRACE_FLAG_RECOVERY;
    return flags;
}

static void trace_sample_if_due(uint64_t now_us) {
    if (!g_trace_active || now_us < g_trace_next_us) {
        return;
    }
    refresh_encoder_count();
    if (g_trace_count >= g_trace_capacity || g_trace_count >= TRACE_MAX_SAMPLES) {
        g_trace_active = false;
        g_trace_full = true;
        return;
    }
    trace_sample_t *sample = &g_trace[g_trace_count++];
    sample->t_us = (uint32_t)(now_us - g_trace_start_us);
    sample->encoder_position = encoder_position();
    sample->command_position = g_command_position;
    sample->following_error = following_error();
    sample->encoder_invalid = g_encoder_invalid_transitions;
    sample->flags = trace_flags();
    g_trace_next_us += g_trace_period_us;
    if (now_us > g_trace_next_us + (uint64_t)g_trace_period_us * 4u) {
        g_trace_next_us = now_us + g_trace_period_us;
    }
}

static void continuous_enabled_safety(uint64_t now_us) {
    if (!g_drive_enabled) {
        return;
    }

    if (g_recovery_active) {
        /* The pre-existing ViX fault is the only condition temporarily
         * tolerated. Once the X4 fault output has returned healthy, any
         * reassertion is a new fault and immediately drops GP11. */
        if (!estop_safe()) {
            latch_and_disable(LATCH_ESTOP);
            return;
        }
        if (limit_pos_active()) {
            latch_and_disable(LATCH_LIMIT_POS);
            return;
        }
        if (limit_neg_active()) {
            latch_and_disable(LATCH_LIMIT_NEG);
            return;
        }
        if (g_encoder_invalid_transitions != g_recovery_invalid_start) {
            latch_and_disable(LATCH_ENCODER_INVALID);
            return;
        }

        if (vix_fault_active()) {
            if (g_recovery_fault_cleared) {
                g_recovery_fault_reasserted = true;
                latch_and_disable(LATCH_VIX_FAULT);
                return;
            }
        } else {
            g_recovery_fault_cleared = true;
        }

        const uint32_t delta = magnitude_i32(
            g_encoder_raw - g_recovery_encoder_start_raw
        );
        if (delta > g_recovery_max_abs_delta) {
            g_recovery_max_abs_delta = delta;
        }
        if (delta > RECOVERY_MAX_DELTA_COUNTS) {
            latch_and_disable(LATCH_FOLLOWING_ERROR);
            return;
        }

        const uint64_t watchdog_us =
            (uint64_t)g_cfg.host_watchdog_ms * 1000u;
        if (watchdog_us > 0u &&
            now_us - g_last_heartbeat_us > watchdog_us) {
            latch_and_disable(LATCH_HOST_WATCHDOG);
            return;
        }
        if (now_us >= g_recovery_deadline_us) {
            recovery_stop(true);
        }
        return;
    }

    if (!estop_safe()) {
        latch_and_disable(LATCH_ESTOP);
        return;
    }
    if (vix_fault_active()) {
        latch_and_disable(LATCH_VIX_FAULT);
        return;
    }
    if (limit_pos_active()) {
        latch_and_disable(LATCH_LIMIT_POS);
        return;
    }
    if (limit_neg_active()) {
        latch_and_disable(LATCH_LIMIT_NEG);
        return;
    }
    if (g_zeroed && magnitude_following_error() > (uint32_t)g_cfg.following_abort_counts) {
        latch_and_disable(LATCH_FOLLOWING_ERROR);
        return;
    }
    const uint64_t watchdog_us = (uint64_t)g_cfg.host_watchdog_ms * 1000u;
    if (watchdog_us > 0u && now_us - g_last_heartbeat_us > watchdog_us) {
        latch_and_disable(LATCH_HOST_WATCHDOG);
    }
}

static void encoder_pio_irq_handler(void) {
    if (pio_interrupt_get(g_encoder_pio, 1u)) {
        pio_interrupt_clear(g_encoder_pio, 1u);
        g_encoder_invalid_transitions++;
        if (g_drive_enabled) {
            latch_and_disable(LATCH_ENCODER_INVALID);
        }
    }
}

static void drive_output_set(bool enable) {
    gpio_put(PIN_DRIVE_ENABLE, enable ? 1 : 0);
    g_drive_enabled = enable;
}

static void recovery_stop(bool timed_out) {
    if (g_recovery_active && g_recovery_started_us != 0u) {
        g_recovery_elapsed_ms = (uint32_t)(
            (time_us_64() - g_recovery_started_us) / 1000u
        );
    }
    drive_output_set(false);
    g_recovery_active = false;
    if (timed_out) {
        g_recovery_timed_out = true;
        g_safety_latched = true;
        g_latch_code = LATCH_RECOVERY_TIMEOUT;
    }
}

static void pio_abort_burst(void) {
    pio_sm_set_enabled(g_step_pio, g_step_sm, false);
    pio_sm_clear_fifos(g_step_pio, g_step_sm);
    pio_interrupt_clear(g_step_pio, 0);
    pio_sm_restart(g_step_pio, g_step_sm);
    /* Re-initialise the program counter at the pull instruction. Merely
     * restarting the SM can leave the PC in the pulse loop after an abort. */
    stepgen_program_init(
        g_step_pio, g_step_sm, g_step_offset, PIN_STEP
    );
}

static void request_abort(bool invalidate_zero_if_moving) {
    g_abort_epoch++;
    g_abort_requested = true;
    if (invalidate_zero_if_moving && g_motion_state == MOTION_MOVING) {
        /* A PIO segment can be stopped between pulses, so the exact number of
         * emitted counts is not reconstructable. Require a fresh ZERO. */
        g_zeroed = false;
    }
}

static void latch_and_disable(latch_code_t code) {
    request_abort(true);
    g_safety_latched = true;
    g_latch_code = code;
    recovery_stop(false);
}

static void gpio_irq_callback(uint gpio, uint32_t events) {
    (void)events;

    if (gpio == PIN_ENCODER_Z) {
        g_z_edges++;
        g_last_z_raw = g_encoder_raw;
        return;
    }

    if (gpio == PIN_VIX_FAULT && vix_fault_active() && !g_recovery_active) {
        latch_and_disable(LATCH_VIX_FAULT);
        return;
    }

    if (gpio == PIN_ESTOP_AUX && !estop_safe()) {
        latch_and_disable(LATCH_ESTOP);
        return;
    }

    if (gpio == PIN_LIMIT_POS && limit_pos_active() && g_motion_direction > 0) {
        latch_and_disable(LATCH_LIMIT_POS);
        return;
    }

    if (gpio == PIN_LIMIT_NEG && limit_neg_active() && g_motion_direction < 0) {
        latch_and_disable(LATCH_LIMIT_NEG);
    }
}

static inline uint32_t magnitude_i32(int32_t value) {
    return value < 0 ? (uint32_t)(-(int64_t)value) : (uint32_t)value;
}

static inline uint32_t magnitude_following_error(void) {
    const int64_t value = (int64_t)following_error();
    return (uint32_t)(value < 0 ? -value : value);
}
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
int main(void) {
    stdio_init_all();

    gpio_init(PIN_DIR);
    gpio_set_dir(PIN_DIR, GPIO_OUT);
    gpio_put(PIN_DIR, 0);

    gpio_init(PIN_DRIVE_ENABLE);
    gpio_set_dir(PIN_DRIVE_ENABLE, GPIO_OUT);
    gpio_put(PIN_DRIVE_ENABLE, 0);

    init_input(PIN_ENCODER_Z);
    init_input(PIN_LIMIT_POS);
    init_input(PIN_LIMIT_NEG);
    init_input(PIN_HOME);
    init_input(PIN_VIX_FAULT);
    init_input(PIN_ESTOP_AUX);

    gpio_set_irq_enabled_with_callback(PIN_ENCODER_Z,
        GPIO_IRQ_EDGE_RISE | GPIO_IRQ_EDGE_FALL, true, &gpio_irq_callback);
    gpio_set_irq_enabled(PIN_VIX_FAULT,
        GPIO_IRQ_EDGE_RISE | GPIO_IRQ_EDGE_FALL, true);
    gpio_set_irq_enabled(PIN_ESTOP_AUX,
        GPIO_IRQ_EDGE_RISE | GPIO_IRQ_EDGE_FALL, true);
    gpio_set_irq_enabled(PIN_LIMIT_POS,
        GPIO_IRQ_EDGE_RISE | GPIO_IRQ_EDGE_FALL, true);
    gpio_set_irq_enabled(PIN_LIMIT_NEG,
        GPIO_IRQ_EDGE_RISE | GPIO_IRQ_EDGE_FALL, true);

    /* The official Raspberry Pi quadrature program uses computed jumps and
     * must occupy PIO instruction address 0. PIO1 is otherwise unused. */
    if (!pio_can_add_program_at_offset(
            g_encoder_pio, &quadrature_encoder_program, 0u)) {
        panic("quadrature encoder PIO program cannot be placed at offset 0");
    }
    g_encoder_offset = pio_add_program_at_offset(
        g_encoder_pio, &quadrature_encoder_program, 0u);
    (void)g_encoder_offset;
    g_encoder_sm = pio_claim_unused_sm(g_encoder_pio, true);
    quadrature_encoder_program_init(
        g_encoder_pio, g_encoder_sm, PIN_ENCODER_A, 0);
    refresh_encoder_count();

    pio_interrupt_clear(g_encoder_pio, 1u);
    irq_set_exclusive_handler(PIO1_IRQ_0, encoder_pio_irq_handler);
    pio_set_irq0_source_enabled(g_encoder_pio, pis_interrupt1, true);
    irq_set_enabled(PIO1_IRQ_0, true);

    g_step_offset = pio_add_program(g_step_pio, &stepgen_program);
    g_step_sm = pio_claim_unused_sm(g_step_pio, true);
    stepgen_program_init(g_step_pio, g_step_sm, g_step_offset, PIN_STEP);

    if (!queue_init(&g_move_queue, sizeof(move_request_t), 1)) {
        panic("motion queue initialization failed");
    }
    multicore_launch_core1(core1_entry);

    sleep_ms(1200);
    printf("{\"event\":\"BOOT\",\"fw\":\"%s\","
           "\"enabled\":false,\"armed\":false,"
           "\"note\":\"Run STATUS, confirm input polarities, ZERO, then ARM\"}\n",
           FW_VERSION);

    char line[LINE_BUFFER_SIZE];
    size_t used = 0;
    latch_code_t last_reported_latch = LATCH_NONE;
    absolute_time_t next_encoder_refresh = make_timeout_time_us(100u);
    g_last_heartbeat_us = time_us_64();

    while (true) {
        if (time_reached(next_encoder_refresh)) {
            refresh_encoder_count();
            update_x5_debounced_inputs();
            next_encoder_refresh = make_timeout_time_us(100u);
        }
        const uint64_t now_us = time_us_64();
        continuous_enabled_safety(now_us);
        trace_sample_if_due(now_us);

        const int ch = getchar_timeout_us(100);
        if (ch != PICO_ERROR_TIMEOUT) {
            if (ch == '\r' || ch == '\n') {
                if (used > 0) {
                    line[used] = '\0';
                    handle_line(line);
                    used = 0;
                }
            } else if (used + 1u < sizeof(line)) {
                line[used++] = (char)ch;
            } else {
                used = 0;
                reply_error("INPUT", "line too long");
            }
        }

        if (g_safety_latched && g_latch_code != last_reported_latch) {
            printf("{\"event\":\"SAFETY_LATCH\",\"latch\":\"%s\","
                   "\"enabled\":false}\n", latch_name(g_latch_code));
            last_reported_latch = g_latch_code;
        }
        if (!g_safety_latched) {
            last_reported_latch = LATCH_NONE;
        }
        tight_loop_contents();
    }
}

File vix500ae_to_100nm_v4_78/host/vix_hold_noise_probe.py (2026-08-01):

#!/usr/bin/env python3
"""No-motion hold/noise/stability discriminator for ViX500AE + Pico2.

V4.62 adds a power-stage/zero-GI/GI-threshold matrix so the field result can
separate motor-enable EMI from proportional/velocity-loop instability and
true integral hunting without any commanded moves.

This script intentionally performs NO commanded moves.  It is meant to run after
Stage 5 has shown that 100 nm moves are possible, but Stage 6 final validation is
failing from startup drift, late settle misses, or intermittent hunting.

It separates four likely cases:
  * OFF drift/noise: mechanical/cable/bench disturbance or encoder signal noise.
  * ON-only noise: servo hold-loop instability or motor-enable EMI.
  * GI-dependent hunting: integral gain too aggressive for final validation.
  * Pico/ViX relative disagreement: encoder-copy / receiver / reference issue.

It writes JSON/CSV evidence and a human-readable HOLD_NOISE_VERDICT.txt.
"""

from __future__ import annotations

import argparse
import csv
import json
import math
import signal
import sys
import time
from dataclasses import asdict
from datetime import datetime
from pathlib import Path
from typing import Any

# Import the commissioned host utilities without duplicating serial/safety logic.
from vix100nm_commission import (  # type: ignore
    CommissionAbort,
    Gains,
    RunLog,
    Pico,
    Vix,
    PICO_FERR_SMOKE,
    configure_pico_policy,
    deenergize_drive,
    energize_drive,
    preflight_with_serial_retry,
    safe_pico_zero,
    temporary_vix_setup,
)

STOP_REQUESTED = False
COUNTS_PER_MM = 100_000
NM_PER_COUNT = 10
VIX500_CR_COUNTS_PER_A_RMS = 62136.0


def signal_handler(signum: int, frame: object) -> None:  # pragma: no cover - field path
    global STOP_REQUESTED
    STOP_REQUESTED = True


def now_stamp() -> str:
    return datetime.now().strftime('%Y%m%d_%H%M%S_%f')


def make_run_dir(root: Path) -> Path:
    path = root / f"{now_stamp()}_hold_noise_probe"
    path.mkdir(parents=True, exist_ok=False)
    return path


def stats(values: list[float]) -> dict[str, float | int | None]:
    if not values:
        return {
            "n": 0,
            "first": None,
            "last": None,
            "min": None,
            "max": None,
            "span": None,
            "drift": None,
            "median": None,
            "p95_abs_from_first": None,
            "p95_abs_from_median": None,
            "rms_from_first": None,
            "slope_counts_per_s": None,
        }
    ordered = sorted(values)
    n = len(values)

    def pct(sorted_values: list[float], q: float) -> float:
        idx = min(len(sorted_values) - 1, max(0, int(math.ceil(q * len(sorted_values)) - 1)))
        return sorted_values[idx]

    median = ordered[n // 2] if n % 2 else 0.5 * (ordered[n // 2 - 1] + ordered[n // 2])
    first = values[0]
    abs_first = sorted(abs(v - first) for v in values)
    abs_med = sorted(abs(v - median) for v in values)
    rms_first = math.sqrt(sum((v - first) ** 2 for v in values) / n)
    return {
        "n": n,
        "first": first,
        "last": values[-1],
        "min": min(values),
        "max": max(values),
        "span": max(values) - min(values),
        "drift": values[-1] - first,
        "median": median,
        "p95_abs_from_first": pct(abs_first, 0.95),
        "p95_abs_from_median": pct(abs_med, 0.95),
        "rms_from_first": rms_first,
        "slope_counts_per_s": None,
    }


def slope(xs: list[float], ys: list[float]) -> float | None:
    if len(xs) < 2 or len(xs) != len(ys):
        return None
    xm = sum(xs) / len(xs)
    ym = sum(ys) / len(ys)
    den = sum((x - xm) ** 2 for x in xs)
    if den == 0:
        return None
    return sum((x - xm) * (y - ym) for x, y in zip(xs, ys)) / den


def read_vix_safe(vix: Vix, name: str) -> int | None:
    try:
        return vix.read_int(name)
    except Exception:
        return None


def sample_phase(
    *,
    vix: Vix,
    pico: Pico,
    log: RunLog,
    run_dir: Path,
    phase_name: str,
    duration_s: float,
    interval_s: float,
    movement_abort_counts: int,
) -> dict[str, Any]:
    rows: list[dict[str, Any]] = []
    start_t = time.monotonic()
    first_pico: int | None = None
    first_raw: int | None = None
    first_vix_pa: int | None = None
    first_invalid: int | None = None
    hard_stop: str | None = None

    while True:
        if STOP_REQUESTED:
            hard_stop = "operator_stop"
            break
        elapsed = time.monotonic() - start_t
        if elapsed >= duration_s:
            break
        try:
            ps = pico.status()
        except Exception as exc:
            hard_stop = f"pico_status_failed: {exc}"
            break
        vix_pa = read_vix_safe(vix, "PA")
        vix_pe = read_vix_safe(vix, "PE")
        vix_cr = read_vix_safe(vix, "CR")
        vix_st2 = None
        with contextlib_suppress():
            vix_st2 = vix.report("R(ST2)")
        faults = None
        with contextlib_suppress():
            faults = vix.faults()

        pico_pos = int(ps.get("encoder_position", 0))
        pico_raw = int(ps.get("encoder_raw", 0))
        invalid = int(ps.get("encoder_invalid", 0))
        if first_pico is None:
            first_pico = pico_pos
            first_raw = pico_raw
            first_vix_pa = vix_pa
            first_invalid = invalid
        row = {
            "elapsed_s": elapsed,
            "pico_encoder_position": pico_pos,
            "pico_encoder_raw": pico_raw,
            "pico_command_position": int(ps.get("command_position", 0)),
            "pico_following_error": int(ps.get("following_error", 0)),
            "pico_latched": bool(ps.get("latched")),
            "pico_latch": str(ps.get("latch")),
            "pico_enabled": bool(ps.get("enabled")),
            "pico_armed": bool(ps.get("armed")),
            "pico_fault_active": bool(ps.get("fault_active")),
            "pico_raw_fault": int(ps.get("raw_fault", -1)),
            "pico_encoder_invalid": invalid,
            "pico_invalid_delta": invalid - (first_invalid if first_invalid is not None else invalid),
            "vix_pa": vix_pa,
            "vix_pe": vix_pe,
            "vix_cr": vix_cr,
            "vix_st2": vix_st2,
            "vix_faults": faults,
        }
        if first_vix_pa is not None and vix_pa is not None and first_pico is not None:
            row["pico_vix_relative_delta"] = (pico_pos - first_pico) - (vix_pa - first_vix_pa)
        else:
            row["pico_vix_relative_delta"] = None
        rows.append(row)
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

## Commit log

2026-08-13 Large organizational change
    [vix_pico_interface.sch]
2026-08-17 Light changes to documentation
    [vix_pico_interface.kicad_sch, vix_pico_interface.sch]
